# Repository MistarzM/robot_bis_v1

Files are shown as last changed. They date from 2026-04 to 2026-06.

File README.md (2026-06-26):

# 6-DoF Mobile Manipulator with YOLOv8 Vision & Distributed Control






Welcome to the repository of my engineering thesis project! This repository contains the software and architecture overview for a custom-built, remotely controlled mobile manipulator. The system integrates a 6-DoF (Degrees of Freedom) 3D-printed robotic arm, a differential drive chassis, and an AI-powered vision module operating in real-time.

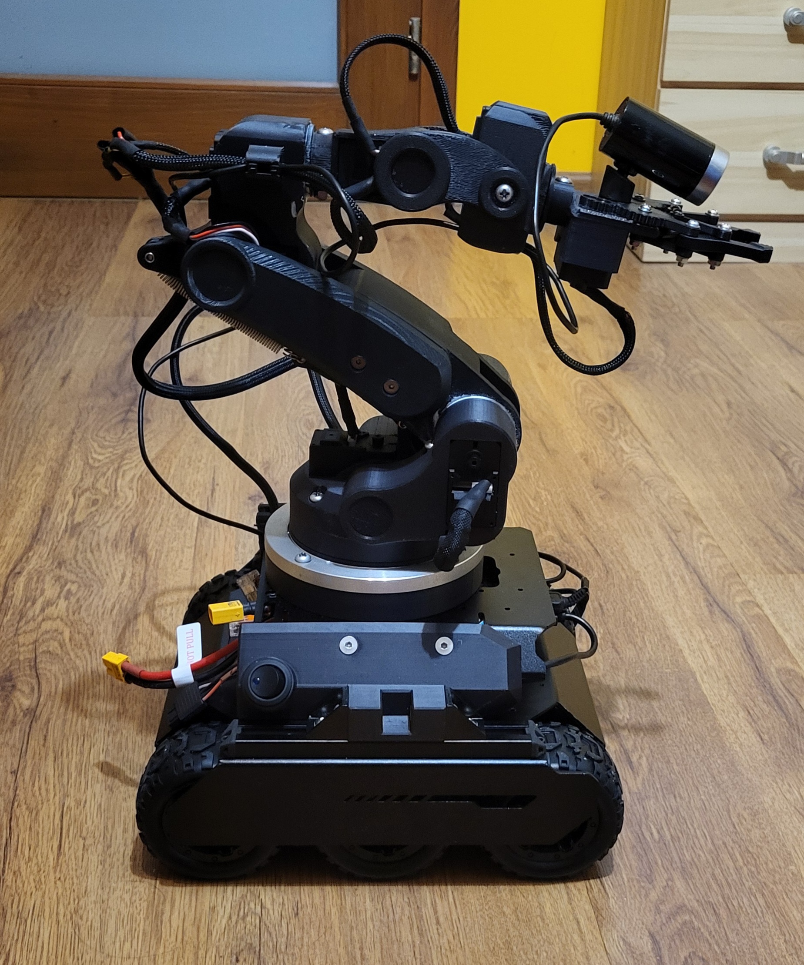
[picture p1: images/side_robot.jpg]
Robot Side View


## 🌟 Key Features

*   **Custom 6-DoF Robotic Arm:** Designed in CAD, 3D printed using high-temperature PolyLite ASA filament, and powered by 8 Waveshare ST3215 serial bus servos (closed-loop).
*   **Analytical Inverse Kinematics (IK):** Custom implementation of Pieper's decoupling method with Denavit-Hartenberg parameters, featuring singularity handling and smooth trajectory generation.
*   **Real-Time AI Vision:** "Eye-in-hand" camera configuration running YOLOv8 Nano for real-time object detection and classification.
*   **Distributed Architecture:** Computations are split between a Controller Node (onboard Raspberry Pi) and a Compute Node (Operator PC) to save power and optimize AI inference.
*   **Low-Latency Communication:** Asynchronous Wi-Fi communication utilizing ZeroMQ (REQ/REP for controls, PUB/SUB for telemetry and video).
*   **Desktop GUI & Gamepad Control:** A fully-featured PySide6 operator station with dynamic keybinding, telemetry dashboard, and live video feed.

## 🛠️ Hardware Architecture

*   **Base:** Waveshare UGV02 (6x4 differential skid-steering platform).
*   **Main Controller Node:** Raspberry Pi 5 (8GB RAM).
*   **Servo Bridge:** ESP32-based Waveshare Servo Driver (handles low-level 1Mbps UART communication with servos).
*   **Actuators:** Waveshare ST3215 bus servos (includes a dual-motor setup on the shoulder joint for doubled torque).
*   **Vision:** A4Tech PK-910H 1080p USB Camera.
*   **Power Management:** Isolated circuits. 3S LiPo (11.1V) for the arm and electronics, and a separate high-current 18650 Li-Ion pack for the chassis motors.

## 💻 Software Architecture

The software is designed as a microservices architecture using Python and ZeroMQ to bypass the Global Interpreter Lock (GIL) and ensure fault tolerance.

### ZeroMQ Topology
ZeroMQ Topology

1.  **Compute Node (Operator Station):** 
    Runs the PySide6 GUI, reads gamepad inputs, performs YOLOv8 inference, and displays telemetry.
2.  **Controller Node (Robot):**
    Uses a Supervisor script to manage three independent processes:
    *   `Arm Service`: Calculates Inverse Kinematics and sends joint targets to the ESP32 bridge.
    *   `Camera Service`: Captures video, compresses it to JPEG, and streams it.
    *   `Chassis Service`: Handles skid-steering logic and velocity ramping (`smooth_step`).

## 🎮 Operator Station (GUI)

The operator station is built with **PySide6** and features a dark-mode interface. It provides full control over the robot, including XYZ cartesian positioning, joint telemetry, and AI vision overlay.

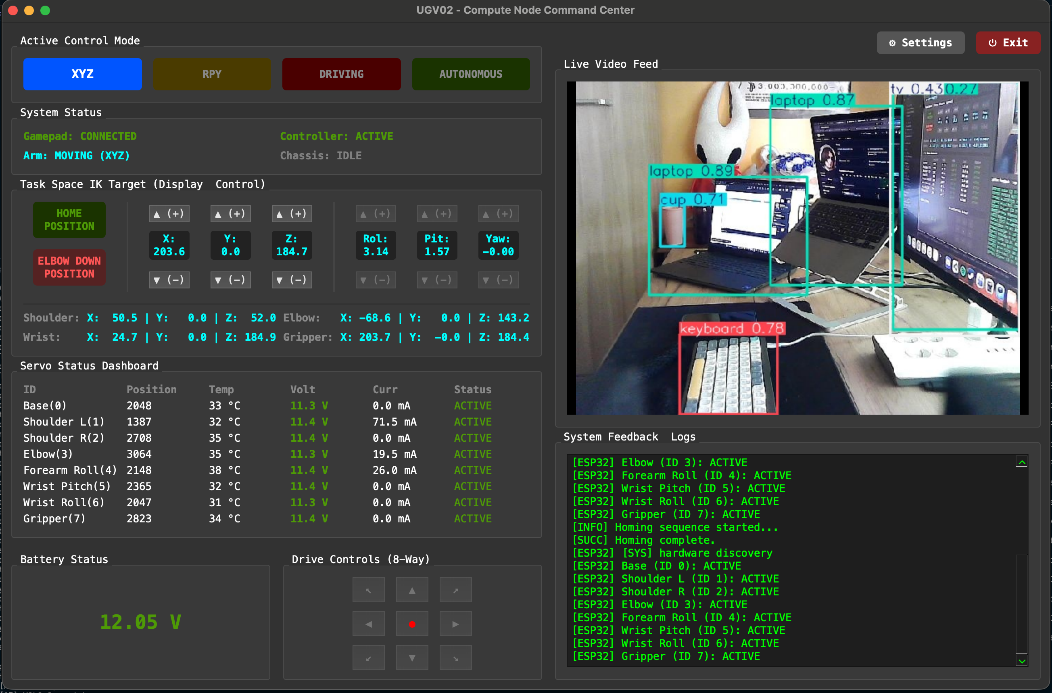
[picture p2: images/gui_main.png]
GUI Main


### Control Modes
The system supports multiple operational modes mapped to a standard Bluetooth gamepad:
*   **XYZ Mode:** Cartesian translation of the end-effector.
*   **RPY Mode:** Orientation control (Roll, Pitch, Yaw).
*   **DRIVING Mode:** Controls the UGV02 chassis with intelligent axis inversion for reverse driving.
*   **AUTONOMOUS:** Placeholder for future ROS 2 and SLAM integration.

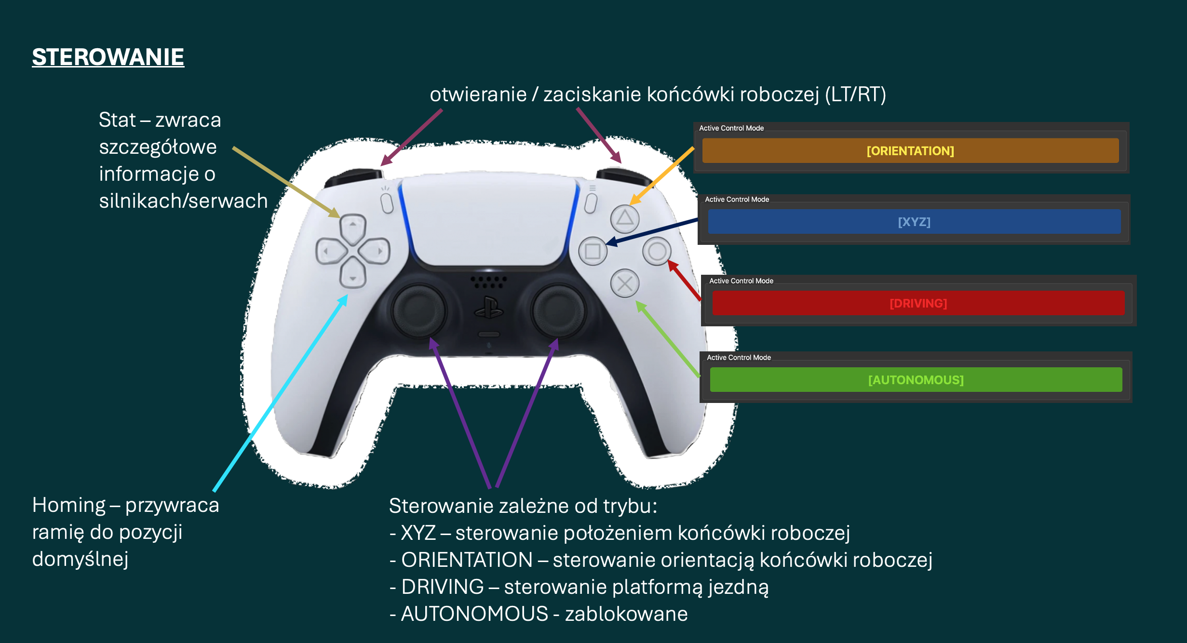
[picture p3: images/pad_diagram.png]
Gamepad Mapping


## 🚀 Getting Started

### Prerequisites
*   Python 3.11+
*   `requirements.txt` (includes `pyzmq`, `opencv-python`, `ultralytics`, `PySide6`, `pygame`, `numpy`)

### Running the System
1.  **On the Robot (Raspberry Pi):**
    ```bash
    python3 controller_main.py
    ```
2.  **On the Operator Station (PC):**
    ```bash
    python3 compute_node.py
    ```
    *Ensure your PC is on the same local Wi-Fi network as the robot.*

## 🔮 Future Development
*   **Custom Chassis:** Replacing the commercial UGV02 with a fully custom base for higher payload capacity and better BMS current limits.
*   **ROS 2 Migration:** Porting the control architecture to ROS 2 for native SLAM, Navigation, and point-cloud support.
*   **Numerical Path Planning:** Adding polynomial trajectory interpolation to avoid internal self-collisions during rapid singular transitions.
*   **Visual Servoing:** Automated object grasping based on YOLOv8 bounding box coordinates.

## 📝 License
This project is for educational and research purposes. Feel free to explore, fork, and modify the codebase!

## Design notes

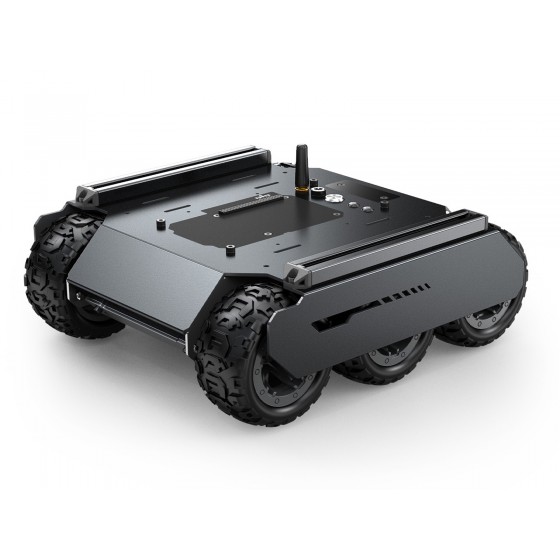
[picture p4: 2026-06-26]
images/ugv02.jpg

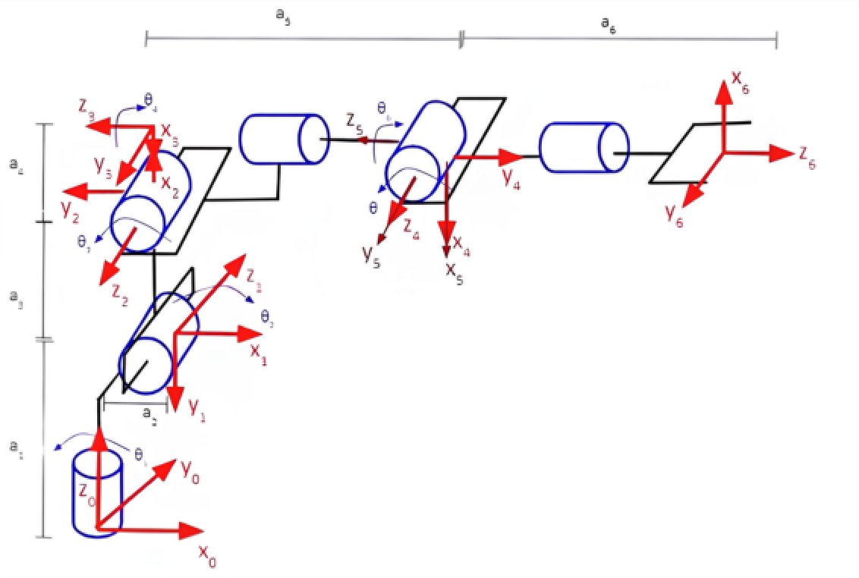
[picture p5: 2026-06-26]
images/dh_frames.png

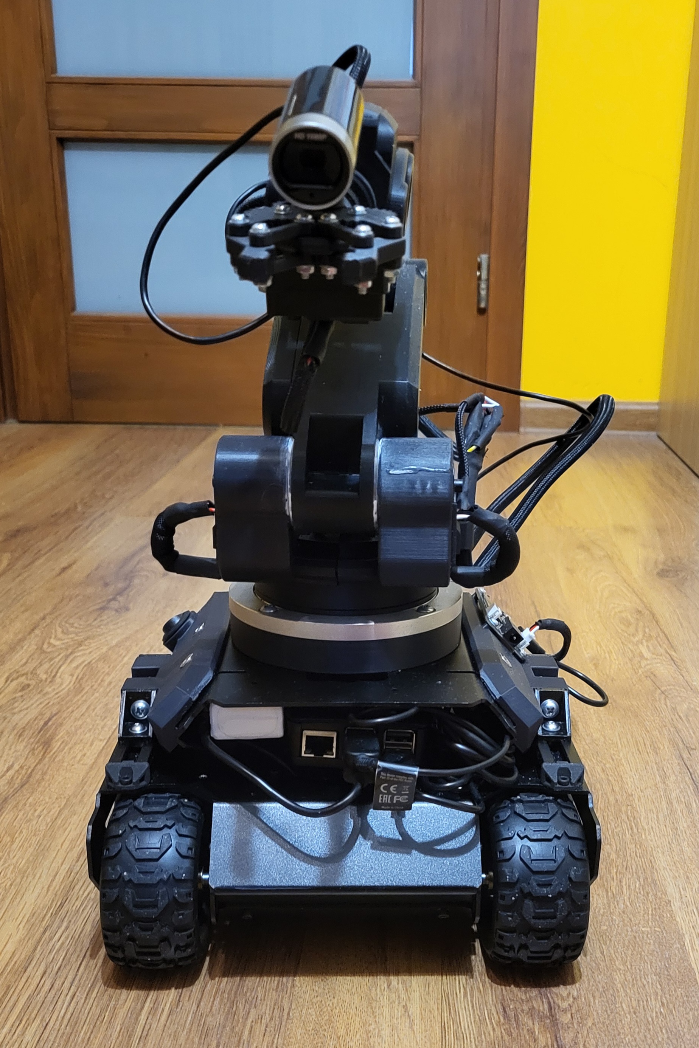
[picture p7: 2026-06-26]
images/front_robot.jpg

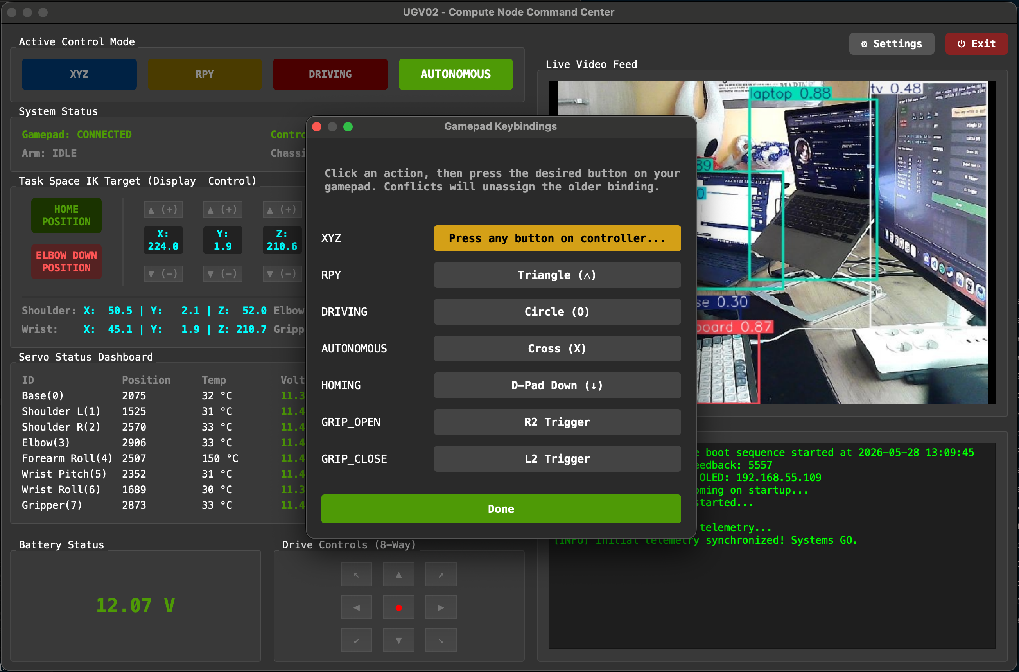
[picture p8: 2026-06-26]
images/gui_settings.png

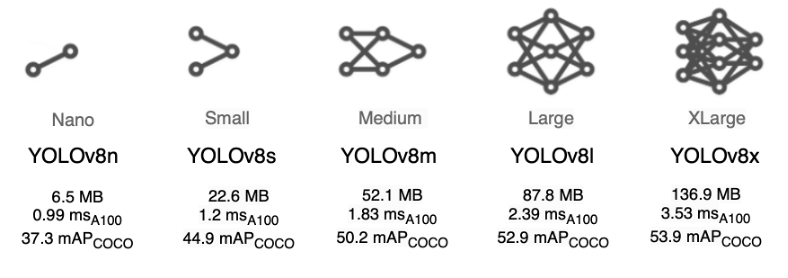
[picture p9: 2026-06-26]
images/yolo_versions.png

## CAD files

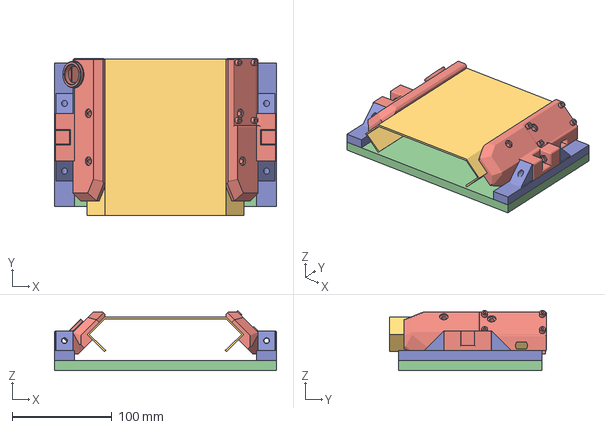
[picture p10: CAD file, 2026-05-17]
robot_parts/add-ons/ugv02_extender_connector.3mf
223.0 x 157.5 x 60.4 mm

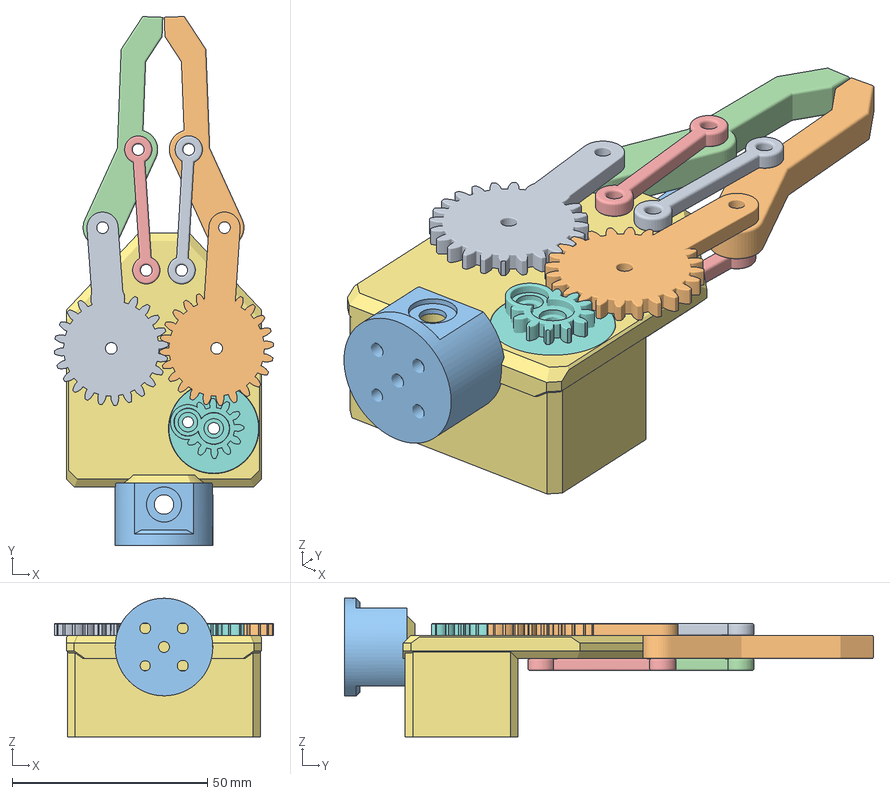
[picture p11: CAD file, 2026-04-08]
robot_parts/arm/v0.1_alpha/gripper_01.3mf
56.2 x 135.5 x 35.5 mm

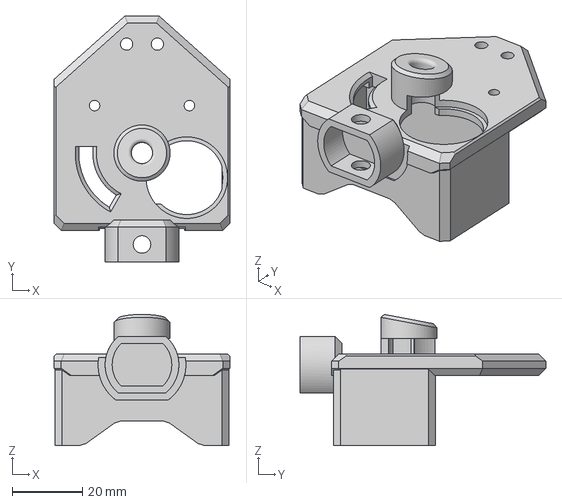
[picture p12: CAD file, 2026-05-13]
robot_parts/arm/v0.5_beta/gripper_04.3mf
50.0 x 70.0 x 37.3 mm

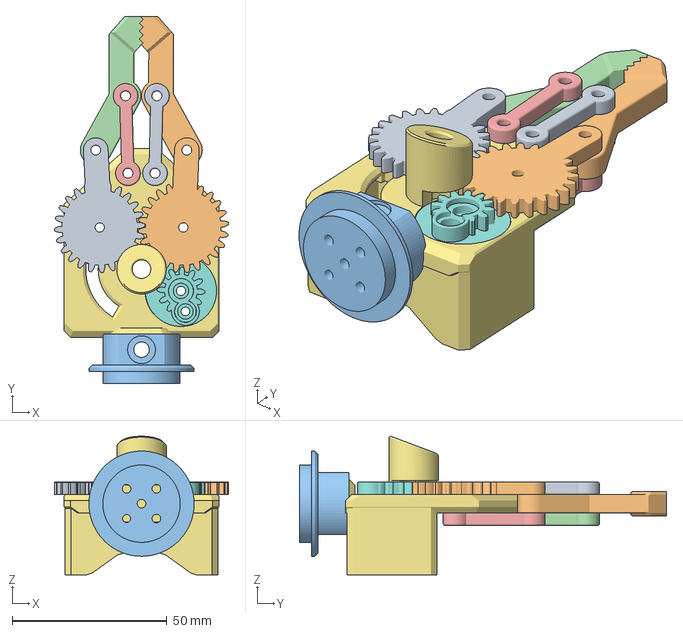
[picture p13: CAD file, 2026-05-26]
robot_parts/arm/v0.9_rc1/gripper_rc1.3mf
56.2 x 118.7 x 44.8 mm

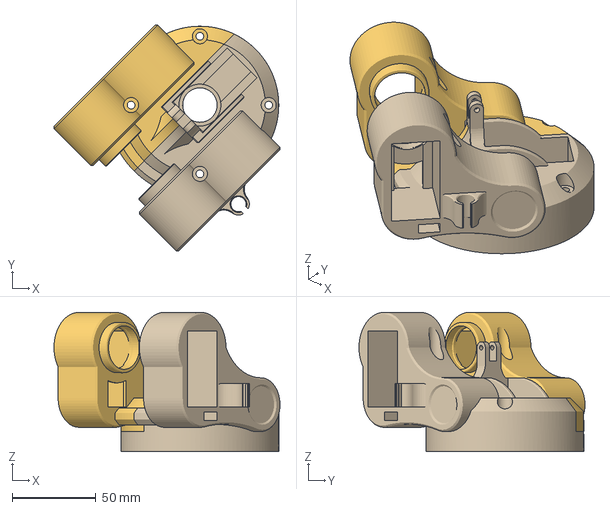
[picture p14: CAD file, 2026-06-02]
robot_parts/arm/v0.9_rc2/shoulder_rc2.3mf
134.7 x 134.7 x 83.0 mm

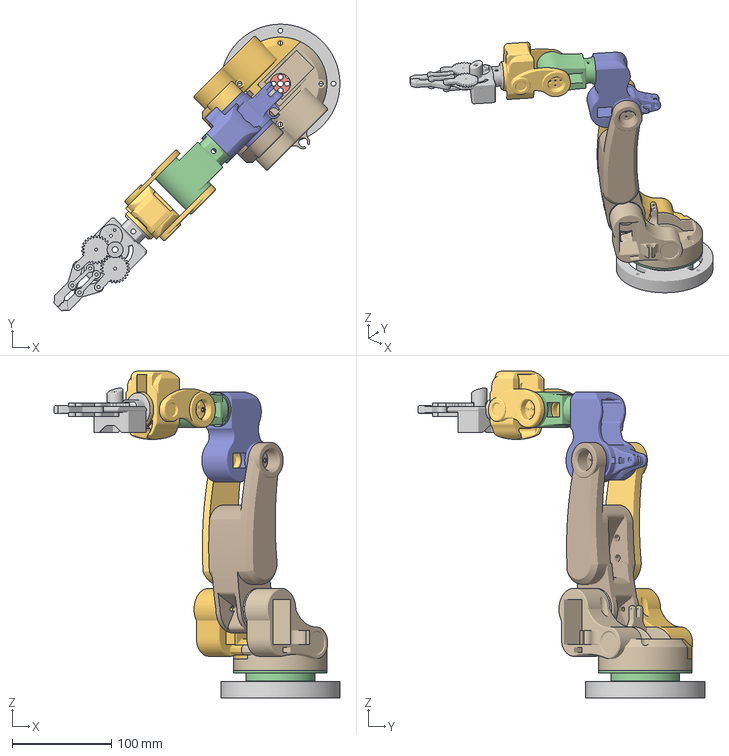
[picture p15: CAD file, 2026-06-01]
robot_parts/arm/v1.0.0/robot_bis_v1.0.3mf
288.0 x 288.8 x 329.5 mm

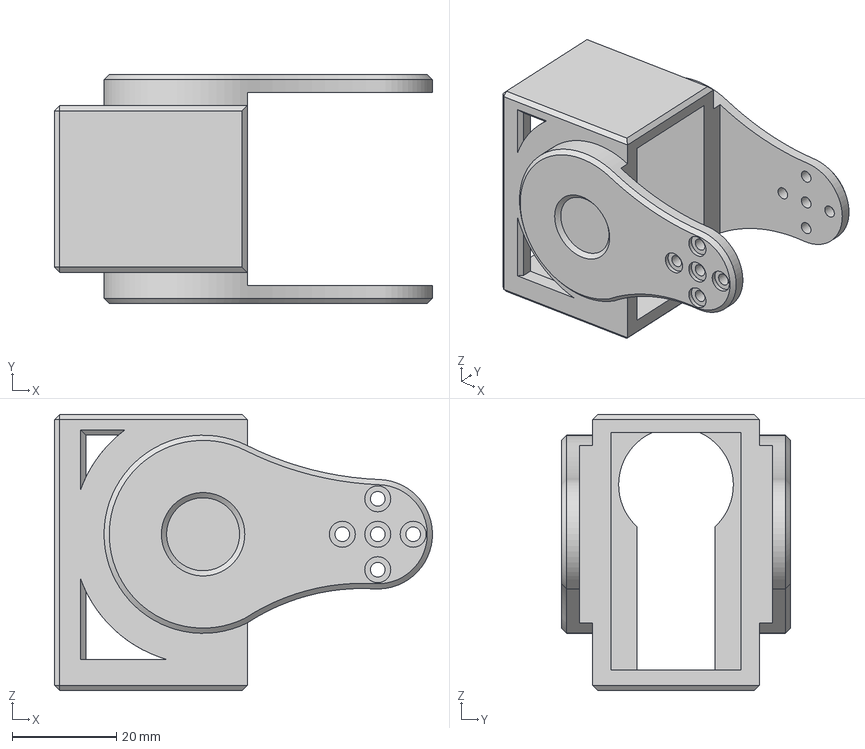
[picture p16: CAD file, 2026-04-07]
robot_parts/arm/v0.1_alpha/wrist_01.3mf
72.5 x 44.0 x 53.0 mm

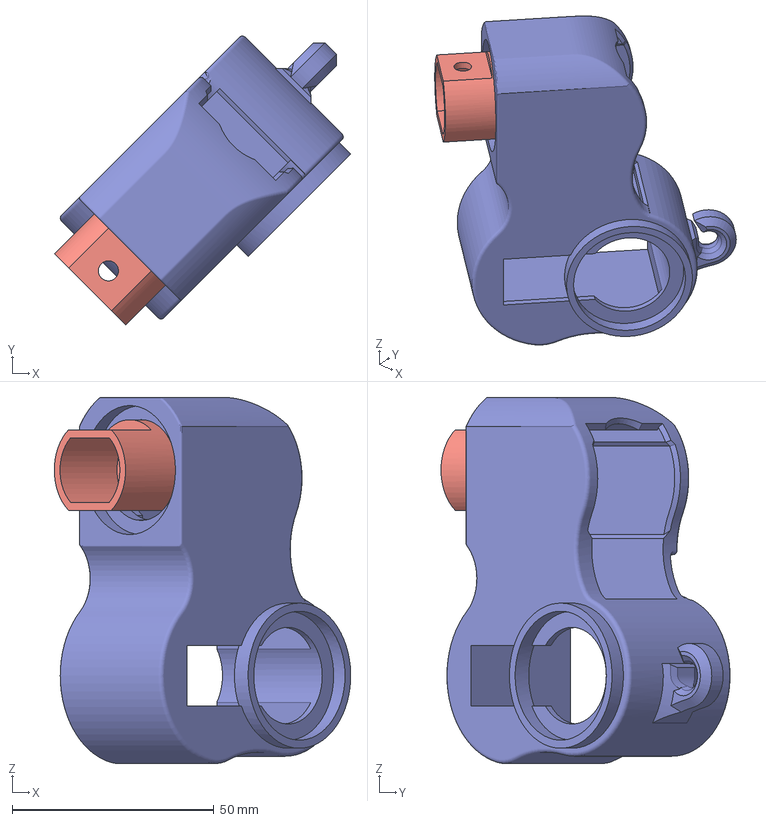
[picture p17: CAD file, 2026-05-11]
robot_parts/arm/v0.5_beta/elbow.3mf
73.5 x 71.7 x 90.8 mm

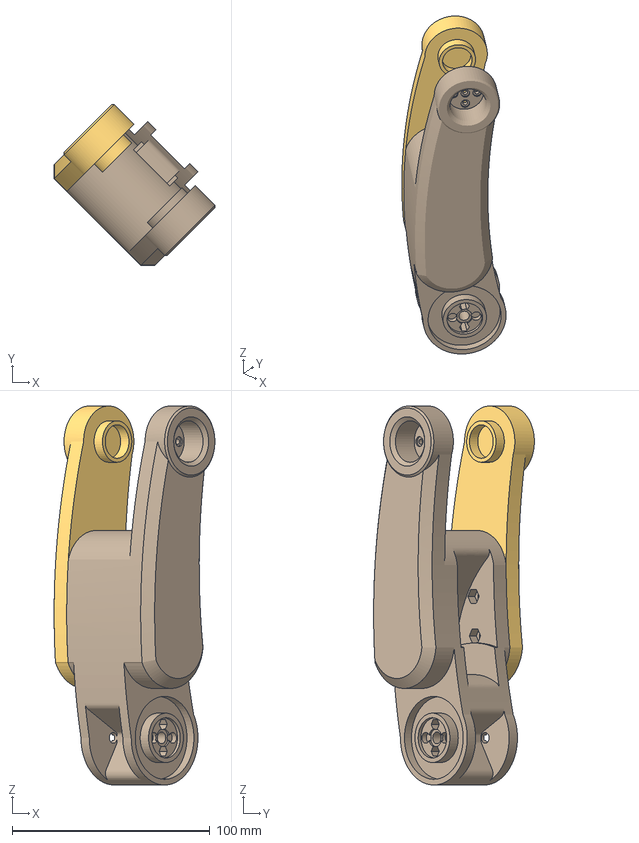
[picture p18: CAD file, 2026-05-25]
robot_parts/arm/v0.9_rc1/upperarm_rc1.3mf
81.4 x 81.4 x 191.9 mm

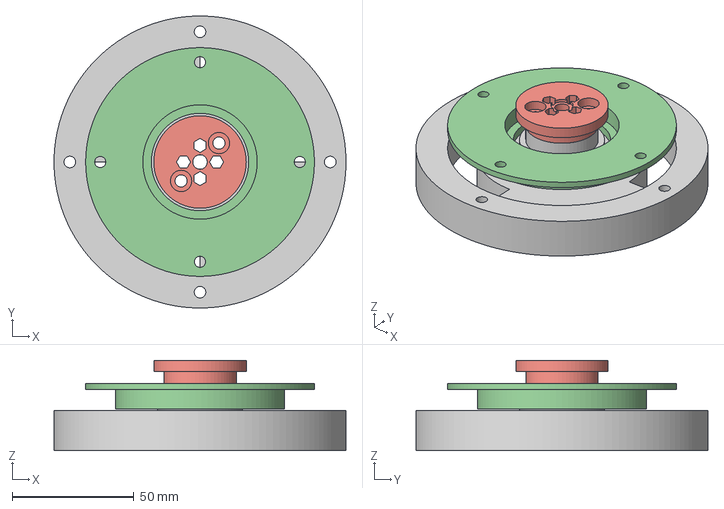
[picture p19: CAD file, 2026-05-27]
robot_parts/arm/v0.9_rc2/base_rc2.3mf
120.0 x 120.0 x 37.0 mm

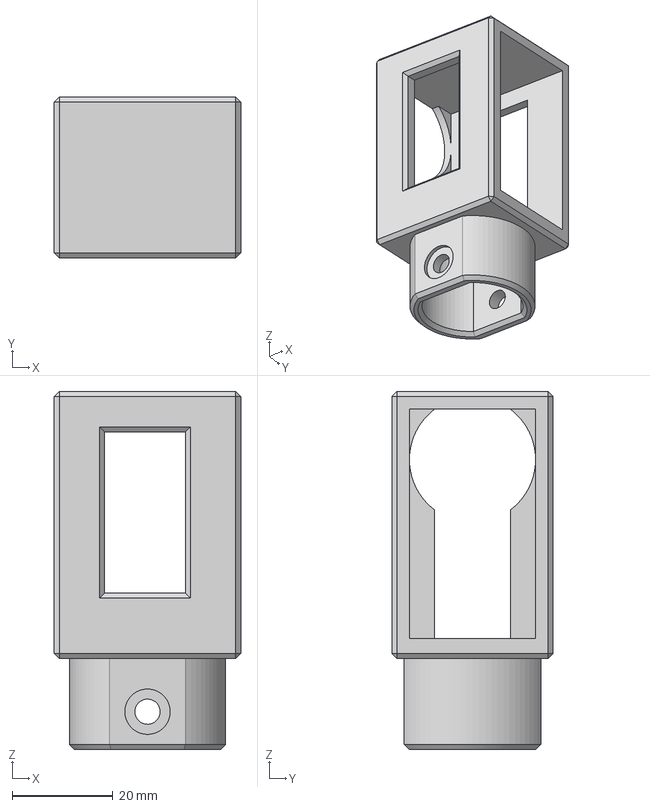
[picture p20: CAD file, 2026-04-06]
robot_parts/arm/v0.1_alpha/forearm_01.3mf
37.0 x 32.0 x 71.0 mm

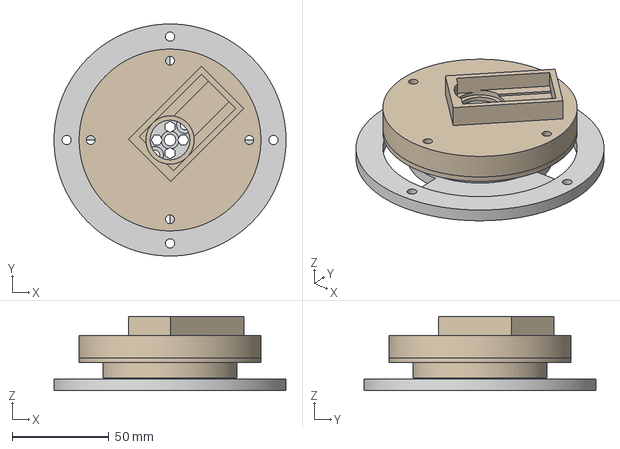
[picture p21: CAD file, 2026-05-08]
robot_parts/arm/v0.5_beta/base_with_bearings_prototype.3mf
120.0 x 120.0 x 38.5 mm

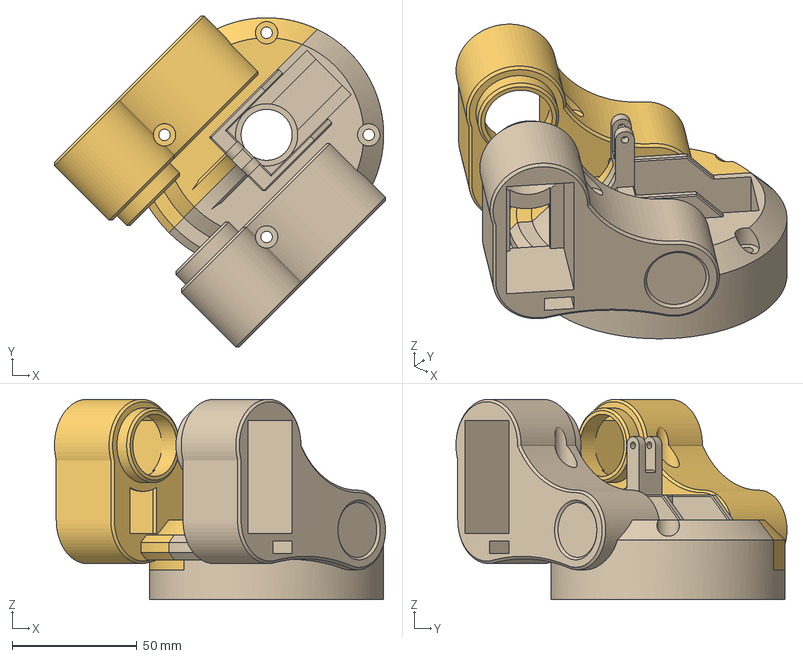
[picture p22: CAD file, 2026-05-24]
robot_parts/arm/v0.9_rc1/shoulder_rc1.3mf
132.9 x 132.9 x 80.5 mm

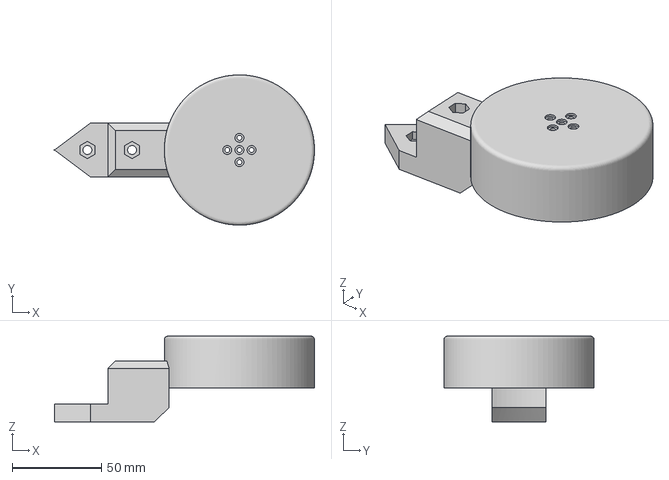
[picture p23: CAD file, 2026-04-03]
robot_parts/arm/v0.1_alpha/upper_arm_02.3mf
145.4 x 84.0 x 48.0 mm

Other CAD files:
robot_parts/arm/v0.5_beta/base_beta.3mf
robot_parts/arm/v0.9_rc1/wrist_rc1.3mf
robot_parts/arm/v0.1_alpha/upper_arm_01.3mf
robot_parts/arm/v0.5_beta/wrist_w_camera.3mf
robot_parts/arm/v0.1_alpha/base_01.3mf
robot_parts/arm/v0.1_alpha/elbow_01.3mf
robot_parts/arm/v0.1_alpha/elbow_02.3mf
robot_parts/arm/v0.1_alpha/elbow_03.3mf
robot_parts/arm/v0.1_alpha/shoulder_01.3mf
robot_parts/arm/v0.5_beta/elbow_02.3mf
robot_parts/arm/v0.5_beta/gripper_02.3mf
robot_parts/arm/v0.9_rc1/base_rc1.3mf
robot_parts/arm/v0.9_rc1/elbow_rc1.3mf
robot_parts/arm/v0.9_rc1/forearm_rc1.3mf

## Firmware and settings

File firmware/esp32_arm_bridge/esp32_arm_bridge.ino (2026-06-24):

#include <SCServo.h>
#include <Wire.h>
#include <Adafruit_GFX.h>
#include <Adafruit_SSD1306.h>

// display 
constexpr uint8_t SCREEN_WIDTH  = 128;
constexpr uint8_t SCREEN_HEIGHT = 32;
constexpr int8_t  OLED_RESET    = -1;
constexpr uint8_t OLED_I2C_ADDR = 0x3C;

Adafruit_SSD1306 display(SCREEN_WIDTH, SCREEN_HEIGHT, &Wire, OLED_RESET);

// servo bus 
constexpr uint32_t SERVO_BAUD    = 1000000;
constexpr int8_t   SERVO_RX_PIN  = 18;
constexpr int8_t   SERVO_TX_PIN  = 19;

// ST3215 register scaling (per datasheet)
constexpr float CURRENT_LSB_MA = 6.5f;   // Present Current  (reg 0x45) — 1 LSB = 6.5 mA
constexpr float VOLTAGE_LSB_V  = 0.1f;   // Present Voltage  (reg 0x3E) — 1 LSB = 0.1 V
constexpr int   POS_MIN        = 0;
constexpr int   POS_MAX        = 4095;

SMS_STS st;

// axes
struct AxisProfile {
  const char* name;
  uint16_t    speed;   // ~steps/s; useful range 0..~3500 (≈ 0.088 °/s per unit)
  uint8_t     accel;   // 0..254 (≈ 100 steps/s² per unit)
};

constexpr uint8_t NUM_AXES = 8;

// index == servo ID
const AxisProfile AXES[NUM_AXES] = {
  { "Base",            2200,   40 },   // 0  J1 yaw — whole-arm inertia

  // dual-drive shoulder pair 
  { "Shoulder L",      2048,   30 },   // 1  J2 pitch (paired with ID 2)
  { "Shoulder R",      2048,   30 },   // 2  J2 pitch (paired with ID 1)

  { "Elbow",           2000,   28 },   // 3  J3 pitch — single motor, longest lever
  { "Forearm Roll",    3500,  120 },   // 4  J4 roll  — paired pace with Wrist Roll
  { "Wrist Pitch",     2400,   60 },   // 5  J5 pitch — lifts gripper against gravity
  { "Wrist Roll",      3500,  120 },   // 6  J6 roll  — paired pace with Forearm Roll
  { "Gripper",         3500,  180 },   // 7  EE      — near-zero inertia, snappy
};

bool servo_active[NUM_AXES] = {false};

// helpers 
static inline bool valid_id(int id) {
  return id >= 0 && id < (int)NUM_AXES;
}

static inline bool in_pos_range(int pos) {
  return pos >= POS_MIN && pos <= POS_MAX;
}

void oled_show(const String& l1, const String& l2 = "") {
  display.clearDisplay();
  display.setTextSize(1);
  display.setTextColor(SSD1306_WHITE);
  display.setCursor(0, 0);
  display.println(l1);
  if (l2.length()) {
    display.setCursor(0, 12);
    display.println(l2);
  }
  display.display();
}

bool write_axis(uint8_t id, int pos) {
  if (!valid_id(id) || !in_pos_range(pos)) return false;
  if (!servo_active[id])                   return false;
  const AxisProfile& a = AXES[id];
  st.WritePosEx(id, pos, a.speed, a.accel);
  return true;
}

void scan_hardware() {
  Serial.println(F("[SYS] hardware discovery"));
  for (uint8_t i = 0; i < NUM_AXES; i++) {
    int pos = st.ReadPos(i);
    servo_active[i] = (pos != -1);

    Serial.print(AXES[i].name);
    Serial.print(F(" (ID "));
    Serial.print(i);
    Serial.print(F("): "));
    Serial.println(servo_active[i] ? F("ACTIVE") : F("NOT FOUND"));
    delay(50);
  }
}

void print_stat() {
  Serial.println(F("[STAT] hardware telemetry"));
  for (uint8_t i = 0; i < NUM_AXES; i++) {
    if (!servo_active[i]) continue;

    int t_raw = st.ReadTemper(i);
    int v_raw = st.ReadVoltage(i);
    int c_raw = st.ReadCurrent(i);

    Serial.print(AXES[i].name);
    Serial.print(F(" (ID "));
    Serial.print(i);
    Serial.print(F(") -> "));

    if (t_raw == -1 || v_raw == -1 || c_raw == -1) {
      Serial.print(F("[ERR] read error ("));
      Serial.print(t_raw); Serial.print(F(","));
      Serial.print(v_raw); Serial.print(F(","));
      Serial.print(c_raw); Serial.println(F(")"));
      continue;
    }

    float volts = v_raw * VOLTAGE_LSB_V;
    float mA    = c_raw * CURRENT_LSB_MA;

    Serial.print(F("Temp: "));       Serial.print(t_raw);  Serial.print(F("C"));
    Serial.print(F(" | Volt: "));    Serial.print(volts, 1); Serial.print(F("V"));
    Serial.print(F(" | Current: ")); Serial.print(mA, 1);  Serial.println(F(" mA"));
  }
}

void handle_move(const String& data) {
  int comma = data.indexOf(',');
  if (comma <= 0) {
    Serial.println(F("[ERR] malformed command"));
    return;
  }

  int id  = data.substring(0, comma).toInt();
  int pos = data.substring(comma + 1).toInt();

  if (!valid_id(id)) {
    Serial.print(F("[ERR] invalid ID ")); Serial.println(id);
    return;
  }
  if (!in_pos_range(pos)) {
    Serial.print(F("[ERR] pos out of range: ")); Serial.println(pos);
    return;
  }
  if (!servo_active[id]) {
    Serial.print(F("[ERR] servo ")); Serial.print(id);
    Serial.println(F(" not active"));
    return;
  }
  if (!write_axis((uint8_t)id, pos)) {
    Serial.println(F("[ERR] write failed"));
  }
}

// arduino 
void setup() {
  Serial.begin(115200);
  Serial1.begin(SERVO_BAUD, SERIAL_8N1, SERVO_RX_PIN, SERVO_TX_PIN);
  st.pSerial = &Serial1;

  if (!display.begin(SSD1306_SWITCHCAPVCC, OLED_I2C_ADDR)) {
    Serial.println(F("[ERR] SSD1306 init failed"));
  }
  oled_show("Waiting for IP...");

  delay(2000);
  scan_hardware();
  Serial.println(F("[SYS] esp32 bridge ready"));
}

void loop() {
  if (!Serial.available()) return;

  String data = Serial.readStringUntil('\n');
  data.trim();
  if (!data.length()) return;

  if (data.startsWith("ip,")) {
    oled_show("Robot IP Address:", data.substring(3));
    Serial.println(F("[SYS] OLED updated with IP"));
  }
  else if (data.equalsIgnoreCase("stat")) {
    print_stat();
  }
  else if (data.equalsIgnoreCase("reset")) {
    scan_hardware();
  }
  else {
    handle_move(data);
  }
}


 

 

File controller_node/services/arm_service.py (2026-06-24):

import time
import zmq
import math
import re
import socket
import os
from core import config
from core.arm_kinematics import ArmKinematics
from hardware.serial_link import Esp32Serial


_RX_ID      = re.compile(r'ID (\d+)')
_RX_TEMP    = re.compile(r'Temp: (\d+)C')
_RX_VOLT    = re.compile(r'Volt: ([\d.]+)V')
_RX_CURRENT = re.compile(r'Current: ([\d.]+)\s*mA')  


class ArmService:
    def __init__(self):
        self.kinematics = ArmKinematics()
        self.serial = Esp32Serial()

        self.context = zmq.Context()
        self.socket = self.context.socket(zmq.REP)
        self.socket.setsockopt(zmq.LINGER, 0)
        self.socket.bind(f"tcp://0.0.0.0:{config.ZMQ_CONTROL_PORT}")

        self.pub_context = zmq.Context()
        self.pub_socket = self.pub_context.socket(zmq.PUB)
        self.pub_socket.bind(f"tcp://127.0.0.1:{config.ZMQ_LOCAL_COMMANDS}")

        self.chassis_sub = self.context.socket(zmq.SUB)
        self.chassis_sub.connect(f"tcp://127.0.0.1:{config.ZMQ_LOCAL_TELEMETRY}")
        self.chassis_sub.setsockopt_string(zmq.SUBSCRIBE, "")

        self.feedback_pub = self.context.socket(zmq.PUB)
        self.feedback_pub.bind(f"tcp://0.0.0.0:{config.ZMQ_FEEDBACK_PORT}")

        _, initial_pose = self.kinematics.get_kinematics(config.ELBOW_DOWN_POS)
        self.target_pose = list(initial_pose)
        self.current_mode = "XYZ"
        self.is_homing = False
        self.arm_status = "IDLE"

        self.sys_logs = []
        self.last_chassis_telemetry = {"voltage": 0.0, "status": "OFFLINE"}
        self.last_stat_request = time.time()

        self.servo_stats = {
            sid: {'temp': '--', 'volt': '--', 'curr': '--', 'status': 'OK'}
            for sid in range(8)
        }

    # helpers
    def _get_local_ip(self):
        try:
            s = socket.socket(socket.AF_INET, socket.SOCK_DGRAM)
            s.connect(("8.8.8.8", 80))
            ip = s.getsockname()[0]
            s.close()
            return ip
        except Exception:
            return "NO NETWORK"

    def _send_shoulder_pair(self, pos_l: int):
        pos_r = config.CALIB_SHOULDER_L + config.CALIB_SHOULDER_R - int(pos_l)
        self.serial.send_command(f"1,{int(pos_l)}\n2,{int(pos_r)}\n")

    def _get_physical_positions(self):
        phys_pos = {}
        max_servo = getattr(config, 'MAX_SERVO', 4095)

        for s_id in [0, 1, 3, 4, 5, 6, 7]:
            base_val = config.ELBOW_DOWN_POS.get(s_id, 2048)
            virt_pos = self.kinematics.pos.get(s_id, base_val)
            delta = virt_pos - base_val

            if s_id in [1, 3]:
                phys_pos[s_id] = base_val - delta
            else:
                phys_pos[s_id] = base_val + delta

        base_1 = config.ELBOW_DOWN_POS.get(1, 2048)
        virt_pos_1 = self.kinematics.pos.get(1, base_1)
        delta_1 = virt_pos_1 - base_1
        phys_pos[2] = config.ELBOW_DOWN_POS.get(2, 2048) + delta_1

        phys_pos[7] = max(0, min(max_servo, phys_pos.get(7, 2048)))
        return phys_pos

    def _parse_stat_line(self, line: str) -> bool:
        if "Temp:" not in line or "Volt:" not in line:
            return False

        id_m   = _RX_ID.search(line)
        temp_m = _RX_TEMP.search(line)
        volt_m = _RX_VOLT.search(line)
        curr_m = _RX_CURRENT.search(line)

        if not id_m:
            return False

        s_id = int(id_m.group(1))
        if s_id not in self.servo_stats:
            return False

        self.servo_stats[s_id].update({
            'status': 'OK',
            'temp':   temp_m.group(1) if temp_m else '--',
            'volt':   volt_m.group(1) if volt_m else '--',
            'curr':   curr_m.group(1) if curr_m else '--',
        })
        return True

    # homing
    def perform_homing(self):
        self.is_homing = True
        self.arm_status = "HOMING"

        msg_start = "[INFO] Homing sequence started..."
        print(msg_start, flush=True)
        self.sys_logs.append(msg_start)

        for s_id in self.servo_stats:
            self.servo_stats[s_id].update({'temp': '--', 'volt': '--', 'curr': '--', 'status': 'OK'})

        self.serial.send_reset()
        time.sleep(2.5)

        _, home_ee_pose = self.kinematics.get_kinematics(config.ELBOW_DOWN_POS)
        self.target_pose = list(home_ee_pose)

        for servo_id in [0, 1, 3, 4, 5, 6, 7]:
            target = config.ELBOW_DOWN_POS.get(servo_id, 2048)
            self.kinematics.pos[servo_id] = target

            if servo_id == 1:
                self._send_shoulder_pair(int(target))
            else:
                self.serial.send_command(f"{servo_id},{int(target)}\n")

            time.sleep(0.4)

        self.is_homing = False
        self.arm_status = "ACTIVE"

        msg_end = "[SUCC] Homing complete."
        print(msg_end, flush=True)
        self.sys_logs.append(msg_end)

    # ZMQ request handling
    def process_request(self, msg):
        if msg.get("command") == "GET_BOOT_LOGS":
            try:
                if os.path.exists("robot.log"):
                    with open("robot.log", "r", encoding="utf-8") as f:
                        lines = f.readlines()
                    return {"status": "OK", "boot_logs": [l.strip() for l in lines if l.strip()]}
                return {"status": "OK", "boot_logs": ["[SYSTEM] No log file found on robot disk yet."]}
            except Exception as e:
                return {"status": "ERROR", "message": str(e)}

        if msg.get("command") == "CONTROL":
            pad = msg.get("pad", {})
            if pad.get("connected") and not self.is_homing:

                if pad.get('btn_square'):   self.current_mode = "XYZ"
                if pad.get('btn_triangle'): self.current_mode = "RPY"
                if pad.get('btn_circle'):   self.current_mode = "DRIVING"
                if pad.get('btn_cross'):    self.current_mode = "AUTONOMOUS"

                self.pub_socket.send_json({"pad": pad, "mode": self.current_mode})

                if self.current_mode in ["XYZ", "RPY"]:
                    moving = (abs(pad.get('lx', 0)) > 0.05 or
                              abs(pad.get('ly', 0)) > 0.05 or
                              abs(pad.get('rx', 0)) > 0.05 or
                              abs(pad.get('ry', 0)) > 0.05)
                    self.arm_status = f"MOVING ({self.current_mode})" if moving else "ACTIVE"

                    if self.current_mode == "XYZ":
                        self.target_pose[0] -= pad.get('ly', 0) * config.SPEED_LINEAR
                        self.target_pose[1] += pad.get('lx', 0) * config.SPEED_LINEAR
                        self.target_pose[2] -= pad.get('ry', 0) * config.SPEED_LINEAR
                    else:
                        self.target_pose[3] -= pad.get('rx', 0) * config.SPEED_ANGULAR
                        self.target_pose[4] += pad.get('ly', 0) * config.SPEED_ANGULAR
                        self.target_pose[5] += pad.get('lx', 0) * config.SPEED_ANGULAR
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

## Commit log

2026-03-31 Added arm control app
2026-04-01 Base model
    [base_01.3mf]
2026-04-01 Added shoulder model
    [shoulder_01.3mf]
2026-04-02 Updated default pos for joints
2026-04-02 Added elbow model
    [elbow_01.3mf, elbow_02.3mf, elbow_03.3mf]
2026-04-03 Added Upperarm model
    [upper_arm_01.3mf, upper_arm_02.3mf]
2026-04-06 Added forearm model
    [forearm_01.3mf]
2026-04-07 Added wrist model
    [wrist_01.3mf]
2026-04-08 Added gripper model
    [gripper_01.3mf]
2026-04-19 Forward kinematic
2026-04-20 Added inverse kinematic
2026-04-21 Improved Inverse Kinematic
2026-04-25 Added camera service
2026-04-26 Added chassis to controller
2026-04-26 Wrong config name - fix
    [arm_service.py]
2026-04-26 Internal communication - fix
    [arm_service.py, chassis_service.py]
2026-04-26 wrong voltage in gui - fix
    [chassis_service.py]
2026-04-26 Fix for log lagging v2
    [arm_service.py]
2026-05-01 Config/dimension of arm changed
2026-05-03 New model for gripper /w camera
    [base_01.3mf, elbow_01.3mf, elbow_02.3mf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]
2026-05-04 Elbow model - beta version
    [elbow_02.3mf]
2026-05-04 Added ip to esp32's display
2026-05-05 Added model for wrist /w camera
    [wrist_w_camera.3mf]
2026-05-05 Added colors for arm's lipo safety
2026-05-07 Added base beta model
    [base_beta.3mf]
2026-05-08 Added base model using bearings
    [base_with_bearings_prototype.3mf]
2026-05-10 Cleaning robot_parts dir
    [base_01.3mf, base_beta.3mf, base_with_bearings_prototype.3mf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]
2026-05-11 Added rc1 - elbow model
    [elbow.3mf]
2026-05-13 Improved gripper model
    [gripper_04.3mf]
2026-05-14 rc1 - cleaning
    [base_with_bearings_prototype.3mf, elbow.3mf, gripper_04.3mf]
2026-05-16 model: base_rc1
    [base_rc1.3mf]
2026-05-17 Added chassis_extender model
    [ugv02_extender_connector.3mf]
2026-05-17 Config arm-dimension updated
2026-05-17 model - strucutre refactor
    [base_01.3mf, base_beta.3mf, base_rc1.3mf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]
2026-05-19 Added base rc1 model
    [base_rc1.3mf]
2026-05-20 Added elbow rc1 model
    [elbow_rc1.3mf]
2026-05-20 shoulder r - display - fix
    [arm_service.py, serial_link.py]
2026-05-21 Added forearm rc1 model
    [forearm_rc1.3mf]
2026-05-22 Added arm - servo limits
2026-05-22 limits display - fix
    [chassis_service.py]
2026-05-24 Added shouder model
    [shoulder_rc1.3mf]
2026-05-27 Added base - rc2 model
    [base_rc2.3mf]
2026-05-28 gripper - binding fix
    [arm_service.py]
2026-05-29 Improved arm + esp32 firmware
2026-06-01 Added v1 model
    [robot_bis_v1.0.3mf]
2026-06-02 Added model
    [shoulder_rc2.3mf]
